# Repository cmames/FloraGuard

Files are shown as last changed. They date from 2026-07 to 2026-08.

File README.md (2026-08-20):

# floraguard

An autonomous, modular, and industrial-grade smart irrigation system powered by an ESP32 and ESP-IDF. Specifically designed to monitor and optimize water delivery for a Rhododendron based on soil moisture kinetics and microclimate atmospheric telemetry.

## Features

- **Decoupled Architecture**: Fully isolated components built under native ESP-IDF v5.2 frameworks (Soil Moisture, Network, BME280 Atmospheric Metrics, Actuators, and SNTP Time Manager).
- **Embedded file system (SPIFFS)**: The HTML/CSS/JS web dashboard is stored as a static file in a dedicated 2 MB flash partition, reducing the RAM footprint to a minimum.
- **Asynchronous web UI**: Dynamic front-end using async JavaScript `fetch()` requests to refresh metrics without page reloads, featuring real-time connection status.
- **Quantized high-precision history**: Real-time soil moisture values are mapped onto an 8-bit scale (0 to 255) to optimize RAM storage while improving graph resolution on the client side.
- **Self-healing network time**: Background FreeRTOS task ensuring automatic SNTP time resynchronization and fallback mechanisms when internet connectivity is lost.
- **Contextual color-coded logging**: Automatic localized ISO 8601 logging (`[YYYY-MM-DD HH:MM:SS]`) mirrored dynamically to the Web UI with warning levels (green for Info, yellow for Warning, red for Error).
- **Advanced Oversampling**: Analog noise reduction layer running sequential reads to smooth out capacitive sensor floating anomalies.
- **Microclimate Telemetry**: Onboard I2C BME280 integration providing live localized temperature, relative humidity, and atmospheric pressure.
- **Agricultural Controls**: Custom background FreeRTOS control loops ensuring the plant stays within safe moisture thresholds while preventing root suffocation.
- **Horticultural Night Restriction**: Localized SNTP time harvesting to enforce daylight-only watering schedules, respecting plant nutrient absorption and respiration cycles.
- **REST JSON API**: Live embedded HTTP server exposing raw and processed operational metrics over local networks.
- **mDNS Network Resolution**: Local discovery accessible via standard zero-config hostnames (`http://floraguard.local`).
- **Power-On Self-Test (POST)**: One-second diagnostic hardware sequence flashing all notification LEDs on boot.

---

## Hardware Configuration

The system utilizes an **ESP32 DevKitC V4** micro-controller. Due to layout restrictions, all active peripherals are mapped onto the fully bidirectional right-side header pins:

| Peripheral | GPIO Pin | Type | Notes |
| :--- | :---: | :---: | :--- |
| **Capacitive Moisture Sensor v1.2** | GPIO34 | Analog Input | Mapped to ADC1 Channel 6 |
| **BME280 SDA** | GPIO25 | I2C Bidirectional | Custom routed Master SDA line |
| **BME280 SCL** | GPIO26 | I2C Bidirectional | Custom routed Master SCL line |
| **Water Pump (MOSFET/Relay)** | GPIO13 | Digital Output | High-isolation push-pull output |
| **LED Blue** | GPIO14 | Digital Output | Network status and HTTP request heartbeat |
| **LED Yellow** | GPIO12 | Digital Output | Soil moisture warning indicator (Dry state) |
| **LED Red** | GPIO27 | Digital Output | Critical error / sensor failure / flooded state |

### Hardware Component - 3D Printing
The custom sub-surface delivery nozzle is located at the root of the project: `stl/Watering_stake.stl`.
- **Material**: **PETG** (mandatory for hydrophobic longevity and bio-chemical soil resistance).
- **Slicing parameters**: 4-5 perimeters for absolute water-tightness under pump head pressure, 0.20mm layer height, low cooling fan (20%), and Gyroid infill at 25%.
- **Design details**: Includes 16 angled distribution orifices ($1.5\text{mm}$) matching the internal surface area of a $6\text{mm}$ standard silicone tube to prevent pump cavitation.

---

## Software Directory Structure

```text
floraguard/
├── components/
│   ├── actuator_manager/   # GPIO Push-Pull LED and Relay handlers
│   ├── bme280_manager/     # I2C abstraction and Bosch sensor interface
│   ├── http_api_manager/   # API HTTP server handlers
│   ├── log_manager/        # Logs and keep history
│   ├── sntp_manager/       # Posix Timezone DB synchronization layer
│   ├── soil_moisture/      # Oversampled ADC analog readings
│   ├── storage_manager/    # SPIFFS partition mounting and VFS drivers
│   └── wifi_manager/       # WiFi Station and mDNS handlers
├── data/
│   └── index.html          # Lightweight asynchronous front-end dashboard
├── src/
│   └── main.c              # Core initialization and FreeRTOS scheduler
├── stl/
│   └── Watering_stake.stl  # Custom 3D printable subsurface emitter
├── config.example.ini      # Global project variable template
├── partitions.csv          # Manual partition layout definition
└── platformio.ini          # PlatformIO compilation environments
```

---

## Configuration & Secret Isolation
All parameters, calibration metrics, credentials, and geographic configurations are completely externalized from the source code.

1. Duplicate the template configuration file at the root of your project:

    ```Bash
    cp config.example.ini config.ini
    ```
2. Edit config.ini with your real network credentials and empirical calibration bounds. (Note: config.ini is strictly ignored by Git settings for security compliance).

Example of an agricultural or time config bloc inside config.ini:

```ini
[agriculture]
build_flags =
    -D SOIL_MOISTURE_CRITICAL_HIGH=65.0f
    -D SOIL_MOISTURE_CRITICAL_LOW=20.0f
    -D IRRIGATION_PUMP_ON_MS=10000
    -D IRRIGATION_PUMP_OFF_MS=50000
    -D WATER_UNTIL_SATURATION=0
    
[time]
build_flags =
    -D SNTP_TIMEZONE=\"CET-1CEST,M3.5.0,M10.5.0/3\"
    -D DAYLIGHT_START_HOUR=8
    -D DAYLIGHT_END_HOUR=18
```

---

## Compilation & Deployment
This project uses the PlatformIO IDE or Core CLI toolchain.

1. Run Sensor Calibration
To fetch your sensor's specific raw bounds (MOISTURE_ADC_MIN_WET and MOISTURE_ADC_MAX_DRY), flash the hardware in calibration mode:

    ```Bash
    pio run -e calibration -t upload && pio device monitor
    ```
    Record the values when dry in the air and wet in water, then write them into your config.ini.

2. Standard Production Mode
    To clear cache files, download managed package extensions, build your source tree, and deploy both the binary application and the web interface assets:

    - Build and upload application code:
    ```bash
    rm -rf .pio
    pio run -e floraguard -t upload
    ```
    - Build and upload filesystem assets (SPIFFS):
    ```bash
    pio run -e floraguard -t uploadfs
    ```
    - Monitor system execution:
    ```bash
    pio device monitor
    ```
    
---

## Network API Specification
Once initialized and bound to your local area network, the device responds to automated REST harvesting tasks.

### Fetch Live Status
- URL: http://floraguard.local/api/status or http://<your_assigned_ip>/api/status
- Method: GET
- Response Payload (application/json):

    ```JSON
    {
        "soil":{
            "raw":1876,
            "moisture_pct":42.07
        },
        "environment":{
            "temperature_c":27.59,
            "humidity_pct":45.70,
            "pressure_hpa":1016.99
        },
        "moisture_history": [115, 115, 114, 114, 120, 150, 255, 255],
        "logs": [
            "[INF] [2026-07-16 11:52:28] WiFi connected. Time synced.",
            "[WRN] [2026-07-16 12:00:05] Alert: Soil dry (<20.00%): 18.50%",
            "[INF] [2026-07-16 12:00:05] Daylight active. Starting a watering cycle..."
        ]
    }
    ```
### HTTP dashboard
- URL: http://floraguard.local/ or http://<your_assigned_ip>/
  
---

## License
This project is open-source and registered under the GNU GPL v3 License. Feel free to fork, adapt, and scale out for your custom botanical arrays.

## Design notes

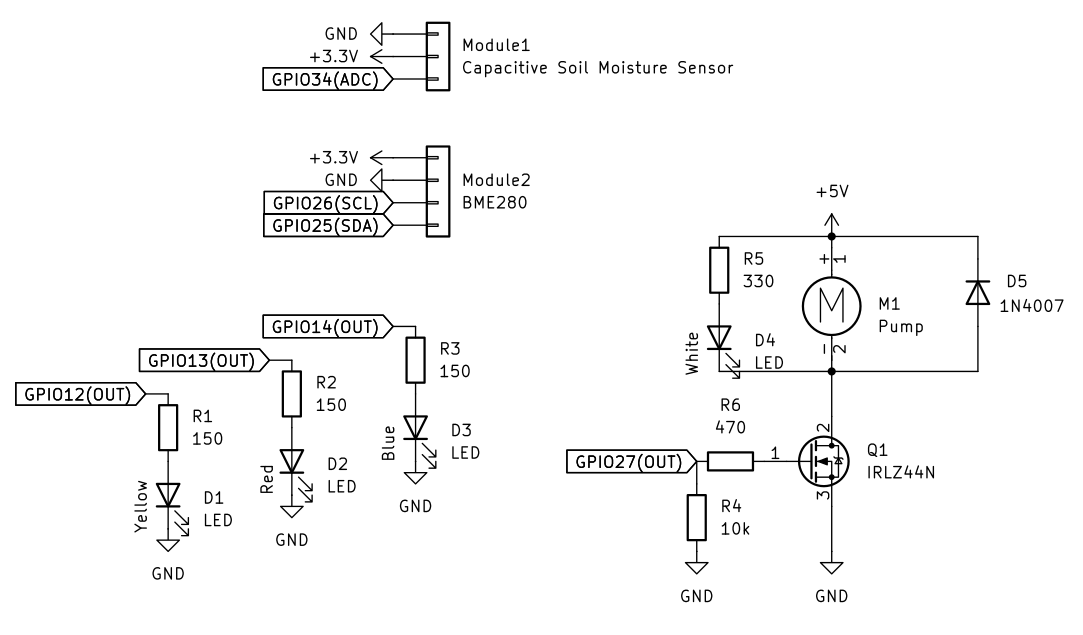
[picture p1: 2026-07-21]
hardware/schematics.png

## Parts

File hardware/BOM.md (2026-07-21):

| Reference | Qty | Value |
| :--- | :--- | :--- |
| D1,D2,D3,D4 | 4 | LED |
| D5 | 1 | 1N4007 |
| M1 | 1 | Pump |
| Module1 | 1 | Capacitive Soil Moisture Sensor |
| Module2 | 1 | BME280 |
| Q1 | 1 | IRLZ44N |
| R1,R2,R3 | 3 | 150 |
| R4 | 1 | 10k |
| R5 | 1 | 330 |
| R6 | 1 | 470 |

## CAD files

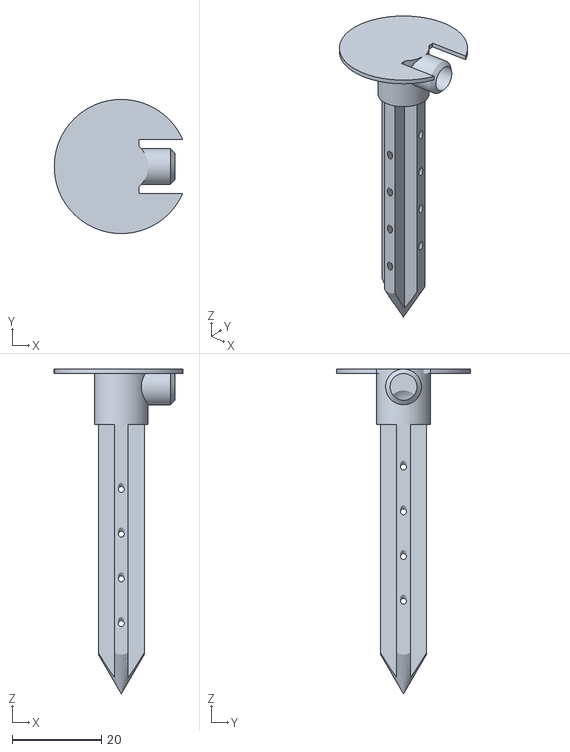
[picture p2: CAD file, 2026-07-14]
stl/watering_stake.stl
28.7 x 30.0 x 72.7

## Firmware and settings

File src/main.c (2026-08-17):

// Copyright (c) 2026 C. Mames - Licensed under the GNU GPL v3
#include <stdio.h>
#include <freertos/FreeRTOS.h>
#include <freertos/task.h>
#include <esp_log.h>
#include <nvs_flash.h>

#include "log_manager.h"
#include "storage_manager.h"
#include "soil_moisture.h"
#include "bme280_manager.h"
#include "actuator_manager.h"
#include "wifi_manager.h"
#include "http_api_manager.h"
#include "sntp_manager.h"

#ifdef RUN_CALIBRATION_MODE
#include "calibration.h"
#endif  

static const char *TAG = "MAIN";

static bool moisture_sensor_failure_tripped = false;

static void watering(float val) {
    LOG_INFO(TAG, "- moisture %.2f%%, watering for %d ms", val, IRRIGATION_PUMP_ON_MS);
    actuator_set_pump(true);
    vTaskDelay(pdMS_TO_TICKS(IRRIGATION_PUMP_ON_MS)); // watering
    actuator_set_pump(false);
    LOG_INFO(TAG, "- Wait %d seconds for the water to soak into the soil", (IRRIGATION_PUMP_OFF_MS/1000));
    vTaskDelay(pdMS_TO_TICKS(IRRIGATION_PUMP_OFF_MS-IRRIGATION_PUMP_ON_MS)); // infiltration
}

static void automation_task(void *pvParameters)
{
    LOG_INFO(TAG, "Control loop automation task started.");
    int night_log_cooldown = 0;

    while (1) {
        int raw_moisture = soil_moisture_get_raw();
        float moisture_pct = soil_moisture_get_percentage();

        log_manager_add_moisture_sample((uint8_t)(moisture_pct * 2.55f));

        // 1. Hardware sensor safety check
        if (raw_moisture <= 0 || raw_moisture >= 4095) {
            LOG_ERROR(TAG, "Critical: Soil moisture sensor fault detected (Raw: %d)!", raw_moisture);
            actuator_set_pump(false);
            actuator_set_led_yellow(false);
            actuator_set_led_red(true);
        } else {
            // 2. Anomaly recovery test: if moisture is back above CRITICAL_LOW, clear the hardware fault flag
            if (moisture_sensor_failure_tripped) {
                if (moisture_pct >= SOIL_MOISTURE_CRITICAL_LOW) {
                    moisture_sensor_failure_tripped = false;
                    LOG_INFO(TAG, "Hardware fault cleared: Soil moisture restored (%.2f%%).", moisture_pct);
                    actuator_set_led_red(false);
                } else {
                    LOG_ERROR(TAG, "Watering is limited due to possible failure. Reset required.");
                    actuator_set_pump(false);
                    actuator_set_led_red(false);
                    vTaskDelay(pdMS_TO_TICKS(500));
                    actuator_set_led_red(true);
                }
            } else {

                // 3. Agricultural control thresholds
                if (moisture_pct > SOIL_MOISTURE_CRITICAL_HIGH) {
                    night_log_cooldown = 0;
                    LOG_WARN(TAG, "Warning: Soil moisture anomaly (>%.0f%%): %.2f%%", SOIL_MOISTURE_CRITICAL_HIGH, moisture_pct);
                    actuator_set_pump(false);
                    actuator_set_led_red(false);
                    actuator_set_led_yellow(true);
                } else {
                    if (moisture_pct < SOIL_MOISTURE_CRITICAL_LOW) {
                        
                        // Only proceed with watering if no persistent failure was tripped
                        if (!moisture_sensor_failure_tripped) {
                            LOG_WARN(TAG, "Alert: Soil dry (<%.0f%%): %.2f%%", SOIL_MOISTURE_CRITICAL_LOW, moisture_pct);
                            actuator_set_pump(false);
                            actuator_set_led_red(false);
                            actuator_set_led_yellow(true);

                            if (is_daylight_hours()) {
                                night_log_cooldown = 0;
                                LOG_INFO(TAG, "Daylight active. Starting a watering cycle...");

                                int safety_counter = 0;
                                const int MAX_WATERING_ATTEMPTS = 10;

                                float previous_moisture = moisture_pct;
                                float last_step_gain = 0.0f;
                                float predicted_next_moisture = 0.0f;

                                do {
                                    watering(moisture_pct);
                                    if (++safety_counter >= MAX_WATERING_ATTEMPTS) {
                                        LOG_ERROR(TAG, "Watering safety timeout reached! Locking system.");
                                        moisture_sensor_failure_tripped = true;
                                        actuator_set_pump(false);
                                        break; // Exit loop immediately on safety trip
                                    }
                                    moisture_pct = soil_moisture_get_percentage();
                                    last_step_gain = moisture_pct - previous_moisture;
                                    if (last_step_gain < 0.0f) {
                                        last_step_gain = 0.0f;
                                    }
                                    predicted_next_moisture = moisture_pct + last_step_gain;
                                    previous_moisture = moisture_pct;
                                    LOG_INFO(TAG, "Step %d: current=%.2f%%, gain=+%.2f%%, predicted_next=%.2f%%", 
                                        safety_counter, moisture_pct, last_step_gain, predicted_next_moisture);
                                } while (
                                    (WATER_UNTIL_SATURATION == 1) && 
                                    (!moisture_sensor_failure_tripped) && 
                                    (moisture_pct < SOIL_MOISTURE_CRITICAL_HIGH) && 
                                    (predicted_next_moisture < SOIL_MOISTURE_CRITICAL_HIGH)
                                );
                                LOG_INFO(TAG, "Watering sequence completed with %d cycles", safety_counter);

                            } else {
                                actuator_set_pump(false);
                                actuator_set_led_yellow(true);
                                if (night_log_cooldown == 0) {
                                    LOG_WARN(TAG, "Alert: Soil dry (<%.0f%%): %.2f%%", SOIL_MOISTURE_CRITICAL_LOW, moisture_pct);
                                    LOG_INFO(TAG, "Nighttime restriction active. Postponing irrigation for 30 minutes.");
                                    night_log_cooldown = 30;
                                } else {
                                    night_log_cooldown--;
                                }
                            }
                        }
                    } 
                    else {
                        // Safe zone: nominal operation
                        actuator_set_pump(false);
                        actuator_set_led_red(false);
                        actuator_set_led_yellow(false);
                    }
                }
            }
        }
        vTaskDelay(pdMS_TO_TICKS(60000));
    }
}

void floraguard(void) 
{
    // Initialize the dynamic log buffer to hold the 5 last lines
    ESP_ERROR_CHECK(log_manager_init(5));
    LOG_INFO(TAG, "FloraGuard logs layer dynamic initialization successful.");

    if (storage_init() != ESP_OK) {
        LOG_ERROR(TAG, "Critical: Filesystem storage mount failed. UI offline.");
    }
    
    if (actuator_manager_init() != ESP_OK) {
        LOG_ERROR(TAG, "Aborting: Actuator framework setup failed.");
        return;
    }

    // Power-On Self-Test (POST) visual check
    actuator_set_pump(true);
    actuator_set_led_blue(true);
    actuator_set_led_yellow(true);
    actuator_set_led_red(true);
    vTaskDelay(pdMS_TO_TICKS(200));
    actuator_set_pump(false);
    vTaskDelay(pdMS_TO_TICKS(800));
    actuator_set_led_blue(false);
    actuator_set_led_yellow(false);
    actuator_set_led_red(false);
    vTaskDelay(pdMS_TO_TICKS(500));
    actuator_set_led_red(true);
    vTaskDelay(pdMS_TO_TICKS(200));
    actuator_set_led_yellow(true);
    actuator_set_led_red(false);
    vTaskDelay(pdMS_TO_TICKS(200));
    actuator_set_led_blue(true);
    actuator_set_led_yellow(false);
    vTaskDelay(pdMS_TO_TICKS(200));
    actuator_set_led_blue(false);
    actuator_set_pump(true);
    vTaskDelay(pdMS_TO_TICKS(200));
    actuator_set_pump(false);



    esp_err_t ret = nvs_flash_init();
    if (ret == ESP_ERR_NVS_NO_FREE_PAGES || ret == ESP_ERR_NVS_NEW_VERSION_FOUND) {
        ESP_ERROR_CHECK(nvs_flash_erase());
        ret = nvs_flash_init();
    }
    ESP_ERROR_CHECK(ret);

    if (soil_moisture_init() != ESP_OK) {
        LOG_ERROR(TAG, "Aborting: Soil moisture hardware setup failed.");
        return;
    }

    if (bme280_manager_init() != ESP_OK) {
        LOG_WARN(TAG, "BME280 setup failed. Running without atmospheric metrics.");
    }

    if (wifi_start(WIFI_SSID, WIFI_PASSWORD, MDNS_HOSTNAME) != ESP_OK) {
        LOG_ERROR(TAG, "Network layer failed to start. Running local mode.");
    } else {
        actuator_set_led_blue(true);
        initialize_sntp();
        if (api_webserver_start() != ESP_OK) {
            LOG_ERROR(TAG, "Critical: Failed to launch local REST API. Web services offline.");
            for(int i=0;i<5;i++) {
                actuator_set_led_blue(false);
                actuator_set_led_red(true);
                vTaskDelay(pdMS_TO_TICKS(500));
                actuator_set_led_blue(true);
                actuator_set_led_red(false);
                vTaskDelay(pdMS_TO_TICKS(500));
            }
        }
    }

    LOG_INFO(TAG, "floraguard firmware fully operational. Launching automation scheduler...");

    xTaskCreatePinnedToCore(automation_task, "automation_task", 4096, NULL, 5, NULL, 1);

    while (1) {
        vTaskDelay(pdMS_TO_TICKS(60000));
    }
}

void app_main(void)
{
#ifdef RUN_CALIBRATION_MODE
    LOG_WARN("ROUTER", "Calibration mode activated.");
    run_calibration();
#else
    LOG_INFO("ROUTER", "Standard application mode starting...");
    floraguard();
#endif
}

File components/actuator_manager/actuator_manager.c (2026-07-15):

// Copyright (c) 2026 C. Mames - Licensed under the GNU GPL v3
#include "actuator_manager.h"
#include <driver/gpio.h>
#include "log_manager.h"

static const char *TAG = "ACTUATOR_MANAGER";

esp_err_t actuator_manager_init(void)
{
    // Configure all 4 pins as push-pull outputs
    gpio_config_t io_conf = {
        .pin_bit_mask = ((1ULL << GPIO_PUMP_OUTPUT)       | 
                         (1ULL << GPIO_LED_BLUE_OUTPUT)   | 
                         (1ULL << GPIO_LED_YELLOW_OUTPUT) | 
                         (1ULL << GPIO_LED_RED_OUTPUT)),
        .mode = GPIO_MODE_OUTPUT,
        .pull_up_en = GPIO_PULLUP_DISABLE,
        .pull_down_en = GPIO_PULLDOWN_DISABLE,
        .intr_type = GPIO_INTR_DISABLE,
    };
    
    esp_err_t err = gpio_config(&io_conf);
    if (err != ESP_OK) {
        LOG_ERROR(TAG, "Failed to configure GPIO configurations.");
        return err;
    }

    // Force safe initial states (All hardware components turned OFF)
    gpio_set_level(GPIO_PUMP_OUTPUT, 0);
    gpio_set_level(GPIO_LED_BLUE_OUTPUT, 0);
    gpio_set_level(GPIO_LED_YELLOW_OUTPUT, 0);
    gpio_set_level(GPIO_LED_RED_OUTPUT, 0);

    LOG_INFO(TAG, "Actuators initialized: Pump:27, LED_Blue:14, LED_Yellow:12, LED_Red:13.");
    return ESP_OK;
}

void actuator_set_pump(bool enable)
{
    gpio_set_level(GPIO_PUMP_OUTPUT, enable ? 1 : 0);
    LOG_DEBUG(TAG, "Pump hardware line altered to: %s", enable ? "ON" : "OFF");
}

void actuator_set_led_blue(bool enable)
{
    gpio_set_level(GPIO_LED_BLUE_OUTPUT, enable ? 1 : 0);
}

void actuator_set_led_yellow(bool enable)
{
    gpio_set_level(GPIO_LED_YELLOW_OUTPUT, enable ? 1 : 0);
}

void actuator_set_led_red(bool enable)
{
    gpio_set_level(GPIO_LED_RED_OUTPUT, enable ? 1 : 0);
}

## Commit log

2026-07-14 feat : watering stake stl file
    [watering_stake.stl]
2026-07-15 feat : new policy and storage_manager
    [partitions.csv]
2026-07-16 feat : add moisture 24h history and NTP synchronization retry if failed
    [main.c]
2026-07-17 fix : real board and dashboard graph
2026-07-21 feat : schematics and BOM
